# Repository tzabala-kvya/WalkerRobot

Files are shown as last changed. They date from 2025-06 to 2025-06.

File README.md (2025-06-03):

# Bluetooth-Controlled Two-Wheel Robot
Author: Tristan Zabala

Date: May 2025

Platform: Arduino Uno

Bluetooth Module: HM-10 (BLE)

Motor Driver: L298N Dual H-Bridge

Control App: Dabble (Gamepad Module)

## Overview
This project enables Bluetooth control of a two-wheel robot using the Dabble mobile app and an HM-10 BLE module. It lets you drive the robot forward, backward, left, and right, and adjust its speed in real time. An emergency stop is also built in for safety.

Features
🔼 Forward, 🔽 Backward, ◀️ Left, and ▶️ Right motion

🔄 Real-time speed control using Dabble Gamepad buttons:

Triangle: Increase speed

Cross: Decrease speed

Square: Reset speed to default (180)

Circle: Emergency stop (sets speed to 0)

📟 Serial Monitor feedback for debugging

🔧 Uses PWM to vary motor speed

## Required Libraries
Dabble Library

SoftwareSerial (included in Arduino IDE)

Install the Dabble library via the Arduino Library Manager or manually from the GitHub link above.

Wiring Diagram
Component	      Arduino Pin
HM-10 TX	      2 (RX via SoftwareSerial)
HM-10 RX	      3 (TX via SoftwareSerial)
HM-10 VCC       5V
HM-10 GND       GND
L298N IN1    	  6
L298N IN2	      7
L298N ENA       (PWM)	10
L298N IN3	      4
L298N IN4	      5
L298N ENB       (PWM)	9

Note: Use a proper power supply for motors; do not power them directly from the Arduino.

## How to Use
Upload the code to your Arduino Uno.

Open the Dabble app and navigate to the Gamepad module.

Connect via BLE to the HM-10 module.
  - If you're using the DSD TECH HM-10, the device will appear as "DSD Tech" in the Dabble app’s Bluetooth scan list. Make sure to select it to establish the connection.

Control the robot using the on-screen D-pad and buttons.

Open Serial Monitor (9600 baud) for live feedback on speed and actions.

Customization
Adjust Speed: Modify baseSpeed to change the robot's default speed.

Motor Logic: The setMotorDirection() function can be changed if your wiring requires reversing the polarity for proper motor direction.

## Troubleshooting

Motors not turning? 
  - Make sure all motor wiring and the external power supply are properly connected and delivering sufficient voltage.
  - Confirm that the L298N motor driver pins are correctly wired to the Arduino and match the pin numbers defined in the code

No response to Dabble? Ensure correct pins and baud rate in Dabble.begin().

License
This project is open-source under the MIT License.

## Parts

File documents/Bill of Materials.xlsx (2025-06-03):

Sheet: 1 Walker
Part Name | Model Quantity | Order Quantity/Walker | Cost(ea.) | Cost(tot.) | number/pack | Order Link
DriveSystem
12V 3000 mAhr Battery | 1 | 1 | $25.79 | $25.79 | 1 | TalentCell Rechargeable 12V DC Output Lithium ion Battery Pack (https://www.amazon.com/TalentCell-Rechargeable-Amplifier-Multi-led-Indicator/dp/B00MHNQIR2)
12V brushed DC motor with Encoder | 2 | 2 | $51.95 | $103.90 | 1 | 70:1 Metal Gearmotor 37Dx70L mm 12V with 64 CPR Encoder (Helical Pinion) (https://www.pololu.com/product/4754)
Arduino Mega 2560 | 1 | 1 | $48.99 | $48.99 | 1 | ARDUINO MEGA 2560 REV3 [A000067] (https://www.amazon.com/ARDUINO-MEGA-2560-REV3-A000067/dp/B0046AMGW0)
L298 Motor Drive Controller Board | 1 | 1 | $14.49 | $14.49 | 1 | L298 (https://www.amazon.com/DKARDU-Controller-Regulator-Optocoupler-Isolation/dp/B0B2RBXTYL?s=electronics)
Pixy2 Smart Vision Sensor | 1 | 1 | $69.90 | $69.90 | 1 | Pixy2 (https://www.amazon.com/Charmed-Labs-Pixy2-Vision-Sensor/dp/B07D1CLYD2)
Pan/Tilit Servo Motor Kit for Pixy2 | 1 | 1 | $29.90 | $29.90 | 1 | PixyCam Pan/Tilt Mount (https://www.amazon.com/Pan-Tilt2-Servo-Motor-Pixy2/dp/B07D1CWJTV?hvadid=309816945299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)
Motor bracket | 2 | 1 | $9.95 | $9.95 | 2 | Pololu Stamped Aluminum L-Bracket Pair for 37D mm Metal Gearmotors (https://www.pololu.com/product/1084)
Motor Mounting Spacer | 2 | 2 |  | $0.00 | 1 | 3D printing
Spur Gear 1.5 modules 39 teeth - TypeA | 2 | 2 |  | $0.00 | 1 | Laser cutting
Spur Gear 1.5 modules 46 teeth - TypeB | 4 | 4 |  | $0.00 | 1 | Laser cutting
Spur Gear 1.5 modules 30 teeth - TypeB | 4 | 4 |  | $0.00 | 1 | Laser cutting
HM-10 Bluetooth Modeule | 1 | 1 | $11.49 | $11.49 | 1 | DSD TECH HM-10 Master and Slave Bluetooth 4.0 LE iBeacon Module (https://www.amazon.com/DSD-TECH-HM-10-Bluetooth-Compatible/dp/B074VXZ1XZ)
ESP32 UWB | 3 | 3 | $39.80 | $119.40 | 1 | https://www.makerfabs.com/esp32-uwb-ultra-wideband.html
Intertial Measurement Unit (IMU) | 1 | 1 | $45.95 | $45.95 | 1 | Amazon.com: Adafruit 9-DOF Absolute Orientation IMU Fusion Breakout - BNO055 : Industrial & Scientific (https://www.amazon.com/Adafruit-Absolute-Orientation-Fusion-Breakout/dp/B017PEIGIG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)
Hardware
0.25in Ball Bearing GB | 8 | 1 | $11.49 | $11.49 | 10 | uxcell FR188-2RS Flanged Ball 1/4" x 1/2" x 3/16" Double Sealed (https://www.amazon.com/dp/B082PPK1L5/ref=emc_b_5_t)
0.25in D-shaft 1.35in | 8 | 8 | $1.39 | $11.12 | 1 | 0.250" (1/4") x 1.375" (1 3/8") Stainless Steel D-Shafting (https://www.servocity.com/0-250-1-4-x-1-375-1-3-8-stainless-steel-d-shafting/)
0.25in D-shaft 1.75in | 4 | 4 | $1.59 | $6.36 | 1 | 1/4" D-Shaft (Stainless Steel, 1-3/4" Length) (https://www.servocity.com/0-250-1-4-x-1-75-1-3-4-stainless-steel-d-shafting/)
0.25in D-shaft 1in | 4 | 4 | $1.19 | $4.76 | 1 | 1/4" D-Shaft (Stainless Steel, 1" Length) (https://www.servocity.com/0-250-1-4-x-1-00-stainless-steel-d-shafting/)
0.25in Non-Flange Ball Bearing | 24 | 12 | $2.19 | $26.28 | 2 | 1/4" ID Non-Flanged Ball Bearing (3/8" OD, 1/8" Thickness) - 2 Pack - ServoCity (https://www.servocity.com/1-4-id-x-3-8-od-non-flanged-ball-bearing-2-pack/)
0.25in Hub M3 Holes | 24 | 12 | $9.95 | $119.40 | 2 | Pololu Universal Aluminum Mounting Hub for 1/4″ (6.35mm) Shaft, M3 Holes (2-Pack) (https://www.pololu.com/product/1994/resources)
3mm Ball Bearing (3mmx8mmx4mm) | 96 | 3 | $11.99 | $35.97 | 20 | Kozelo 20pcs F693ZZ Flanged Ball Bearing - [3x8x4mm] (https://www.amazon.com/Kozelo-20pcs-F693ZZ-Flanged-Bearing/dp/B0B8BSCHXS)
0.25in Shaft Collar | 8 | 2 | $7.99 | $15.98 | 4 | AZSSMUK 1/4" Bore Solid Steel Style Zinc Plated Set Screw Shaft Collars (https://www.amazon.com/Aobbmok-Solid-Steel-Plated-Collars/dp/B07BTV2WQW)
M3 Steel Hex Nut | 52 | 1 | $4.73 | $4.73 | 100 | 18-8 Stainless Steel Hex Nut, M3 x 0.5 mm Thread (https://www.mcmaster.com/products/hex-nuts/?s=steel+hex+nuts)
M3*6 mm Steel Pan Head Phillips Screw | 8 | 1 | $7.03 | $7.03 | 100 | Passivated 18-8 Stainless Steel Pan Head Phillips Screws, M3 x 0.5mm Thread, 6mm Long (https://www.mcmaster.com/92000A116/)
M3*12 mm Steel Pan Head Phillips Screw | 84 | 1 | $6.65 | $6.65 | 100 | Passivated 18-8 Stainless Steel Pan Head Phillips Screws M3 x 0.5mm Thread, 12mm Long (https://www.mcmaster.com/92000A122/)
M3*16 mm Steel Pan Head Phillips Screw | 28 | 1 | $7.60 | $7.60 | 100 | Passivated 18-8 Stainless Steel Pan Head Phillips Screws M3 x 0.5mm Thread, 16mm Long (https://www.mcmaster.com/92000A126/)
M3*25 mm Steel Pan Head Phillips Screw | 24 | 1 | $8.83 | $8.83 | 100 | Passivated 18-8 Stainless Steel Pan Head Phillips Screws M3 x 0.5mm Thread, 25mm Long (https://www.mcmaster.com/92000A130/)
M3*30 mm Steel Pan Head Phillips Screw | 8 | 1 | $9.38 | $9.38 | 100 | Passivated 18-8 Stainless Steel Pan Head Phillips Screws M3 x 0.5mm Thread, 30mm Long (https://www.mcmaster.com/92000A132/)
M3*45 mm Steel Pan Head Phillips Screw | 4 | 1 | $15.80 | $15.80 | 100 | Passivated 18-8 Stainless Steel Pan Head Phillips Screws M3 x 0.5mm Thread, 45mm Long (https://www.mcmaster.com/92000A138/)
M3 Washer | 24 | 1 | $3.42 | $3.42 | 100 | General Purpose 18-8 Stainless Steel Washer for M3 Screw Size, 3.200 mm ID, 6 mm OD (https://www.mcmaster.com/98689A112/)
Hub 6mm ID, 10mm length | 2 | 1 | $8.49 | $8.49 | 4 | Sydien 4Pcs Silver 6mm Rigid Flange Shaft Coupling Motor Guide (https://www.amazon.com/dp/B07R77ZGNN/ref=twister_B07R459BG7?_encoding=UTF8&th=1)
M3 Nut Strip - 56mm | 4 | 2 | $3.50 | $7.00 | 1 | M3 Nut Strip - 56mm (https://www.revrobotics.com/rev-41-1733/)
M3 x 100mm Fully Threaded Rod | 4 | 1 | $10.19 | $10.19 | 15 | uxcell 15Pcs M3 x 100mm Fully Threaded Rod (https://www.amazon.com/uxcell-Threaded-Stainless-Threads-M3-0-5/dp/B09L7R8NRQ?s=hi)
Outside Gear Cover | 4 | 4 |  | $0.00 | 1 | 3D printing
Spacer 12.73mm | 12 | 12 |  | $0.00 | 1 | 3D printing
Spacer 19.74mm | 4 | 4 |  | $0.00 | 1 | 3D printing
Spacer 1mm GB | 8 | 8 |  | $0.00 | 1 | 3D printing
Spacer 2mm | 32 | 32 |  | $0.00 | 1 | 3D printing
Spacer 7.2mm | 8 | 8 |  | $0.00 | 1 | 3D printing
Spacer 7.73mm | 8 | 8 |  | $0.00 | 1 | 3D printing
Spacer 9mm | 8 | 8 |  | $0.00 | 1 | 3D printing
Links
Binary Link 1 | 16 | 16 |  | $0.00 | 1 | Laser cutting
Binary Link 2 | 8 | 8 |  | $0.00 | 1 | Laser cutting
Foot | 16 | 16 |  | $0.00 | 1 | Laser cutting
Ternary links-crank | 16 | 16 |  | $0.00 | 1 | Laser cutting
Ternary links | 8 | 8 |  | $0.00 | 1 | Laser cutting
Structure
AT-AT Side-6mm*12'*20' Wood | 2 | 2 |  | $0.00 | 1 | Laser cutting
Chassis base-6mm*6'*15' Wood | 1 | 1 |  | $0.00 | 1 | Laser cutting
 |  |  | Single Walker Cost |  | $800.24

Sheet: Class Walker
Part Name | Model Quantity | # of Walkers | # / Pack | # of Packs | Cost(ea.) | Cost(tot.) | Order Link
DriveSystem
12V 3000 mAhr Battery | 1 | 4 | 1 | 1 | $25.79 | $25.79 | TalentCell Rechargeable 12V DC Output Lithium ion Battery Pack (https://www.amazon.com/TalentCell-Rechargeable-Amplifier-Multi-led-Indicator/dp/B00MHNQIR2)
12V brushed DC motor with Encoder | 2 |  | 1 | 2 | $51.95 | $103.90 | 70:1 Metal Gearmotor 37Dx70L mm 12V with 64 CPR Encoder (Helical Pinion) (https://www.pololu.com/product/4754)
Arduino UNO | 1 |  | 1 | 1 | $48.99 | $48.99 | Arduino UNO (https://www.digikey.com/en/products/detail/arduino/ABX00080/20371542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)
L298 Motor Drive Controller Board | 1 |  | 2 | 1 | $7.00 | $7.00 | L298N (https://www.amazon.com/Controller-H-Bridge-Stepper-Control-Mega2560/dp/B0DPPWFZ1C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)
Motor bracket | 2 |  | 2 | 1 | $20.00 | $20.00 | Pololu Stamped Aluminum L-Bracket Pair for 37D mm Metal Gearmotors (https://www.pololu.com/product/1084)
Motor Mounting Spacer | 2 |  | 1 | 2 |  | $0.00 | 3D printing
Spur Gear 1.5 modules 39 teeth - TypeA | 2 |  | 1 | 2 |  | $0.00 | Laser cutting
Spur Gear 1.5 modules 46 teeth - TypeB | 4 |  | 1 | 4 |  | $0.00 | Laser cutting
Spur Gear 1.5 modules 30 teeth - TypeB | 4 |  | 1 | 4 |  | $0.00 | Laser cutting
HM-10 Bluetooth Modeule | 1 |  | 1 | 1 | $11.49 | $11.49 | DSD TECH HM-10 Master and Slave Bluetooth 4.0 LE iBeacon Module (https://www.amazon.com/DSD-TECH-HM-10-Bluetooth-Compatible/dp/B074VXZ1XZ)
Hardware
0.25in Ball Bearing GB | 8 | 4 | 10 | 1 | $11.49 | $11.49 | uxcell FR188-2RS Flanged Ball 1/4" x 1/2" x 3/16" Double Sealed (https://www.amazon.com/dp/B082PPK1L5/ref=emc_b_5_t)
0.25in D-shaft 1.35in | 8 |  | 1 | 8 | $1.39 | $11.12 | 0.250" (1/4") x 1.375" (1 3/8") Stainless Steel D-Shafting (https://www.servocity.com/0-250-1-4-x-1-375-1-3-8-stainless-steel-d-shafting/)
0.25in D-shaft 1.75in | 4 |  | 1 | 4 | $1.59 | $6.36 | 1/4" D-Shaft (Stainless Steel, 1-3/4" Length) (https://www.servocity.com/0-250-1-4-x-1-75-1-3-4-stainless-steel-d-shafting/)
0.25in D-shaft 1in | 4 |  | 1 | 4 | $1.19 | $4.76 | 1/4" D-Shaft (Stainless Steel, 1" Length) (https://www.servocity.com/0-250-1-4-x-1-00-stainless-steel-d-shafting/)
0.25in Non-Flange Ball Bearing | 24 |  | 2 | 12 | $2.19 | $26.28 | 1/4" ID Non-Flanged Ball Bearing (3/8" OD, 1/8" Thickness) - 2 Pack - ServoCity (https://www.servocity.com/1-4-id-x-3-8-od-non-flanged-ball-bearing-2-pack/)
0.25in Hub M3 Holes | 24 |  | 2 | 12 | $9.95 | $119.40 | Pololu Universal Aluminum Mounting Hub for 1/4″ (6.35mm) Shaft, M3 Holes (2-Pack) (https://www.pololu.com/product/1994/resources)
3mm Ball Bearing (3mmx8mmx4mm) | 96 |  | 20 | 5 | $11.99 | $59.95 | Kozelo 20pcs F693ZZ Flanged Ball Bearing - [3x8x4mm] (https://www.amazon.com/Kozelo-20pcs-F693ZZ-Flanged-Bearing/dp/B0B8BSCHXS)
0.25in Shaft Collar | 8 |  | 4 | 2 | $7.99 | $15.98 | AZSSMUK 1/4" Bore Solid Steel Style Zinc Plated Set Screw Shaft Collars (https://www.amazon.com/Aobbmok-Solid-Steel-Plated-Collars/dp/B07BTV2WQW)
M3 Steel Hex Nut | 52 |  | 100 | 1 | $4.73 | $4.73 | 18-8 Stainless Steel Hex Nut, M3 x 0.5 mm Thread (https://www.mcmaster.com/products/hex-nuts/?s=steel+hex+nuts)
M3*6 mm Steel Pan Head Phillips Screw | 8 |  | 100 | 1 | $7.03 | $7.03 | Passivated 18-8 Stainless Steel Pan Head Phillips Screws, M3 x 0.5mm Thread, 6mm Long (https://www.mcmaster.com/92000A116/)
M3*12 mm Steel Pan Head Phillips Screw | 84 |  | 100 | 1 | $6.65 | $6.65 | Passivated 18-8 Stainless Steel Pan Head Phillips Screws M3 x 0.5mm Thread, 12mm Long (https://www.mcmaster.com/92000A122/)
M3*16 mm Steel Pan Head Phillips Screw | 28 |  | 100 | 1 | $7.60 | $7.60 | Passivated 18-8 Stainless Steel Pan Head Phillips Screws M3 x 0.5mm Thread, 16mm Long (https://www.mcmaster.com/92000A126/)
M3*25 mm Steel Pan Head Phillips Screw | 24 |  | 100 | 1 | $8.83 | $8.83 | Passivated 18-8 Stainless Steel Pan Head Phillips Screws M3 x 0.5mm Thread, 25mm Long (https://www.mcmaster.com/92000A130/)
M3*30 mm Steel Pan Head Phillips Screw | 8 |  | 100 | 1 | $9.38 | $9.38 | Passivated 18-8 Stainless Steel Pan Head Phillips Screws M3 x 0.5mm Thread, 30mm Long (https://www.mcmaster.com/92000A132/)
M3*45 mm Steel Pan Head Phillips Screw | 4 |  | 100 | 1 | $15.80 | $15.80 | Passivated 18-8 Stainless Steel Pan Head Phillips Screws M3 x 0.5mm Thread, 45mm Long (https://www.mcmaster.com/92000A138/)
M3 Washer | 24 |  | 100 | 1 | $3.42 | $3.42 | General Purpose 18-8 Stainless Steel Washer for M3 Screw Size, 3.200 mm ID, 6 mm OD (https://www.mcmaster.com/98689A112/)
Hub 6mm ID, 10mm length | 2 |  | 4 | 1 | $8.49 | $8.49 | Sydien 4Pcs Silver 6mm Rigid Flange Shaft Coupling Motor Guide (https://www.amazon.com/dp/B07R77ZGNN/ref=twister_B07R459BG7?_encoding=UTF8&th=1)
M3 Nut Strip - 56mm | 4 |  | 1 | 4 | $3.50 | $14.00 | M3 Nut Strip - 56mm (https://www.revrobotics.com/rev-41-1733/)
M3 x 100mm Fully Threaded Rod | 4 |  | 15 | 1 | $10.19 | $10.19 | uxcell 15Pcs M3 x 100mm Fully Threaded Rod (https://www.amazon.com/uxcell-Threaded-Stainless-Threads-M3-0-5/dp/B09L7R8NRQ?s=hi)
Outside Gear Cover | 4 |  | 1 | 4 |  | $0.00 | 3D printing
Spacer 12.73mm | 12 |  | 1 | 12 |  | $0.00 | 3D printing
Spacer 19.74mm | 4 |  | 1 | 4 |  | $0.00 | 3D printing
Spacer 1mm GB | 8 |  | 1 | 8 |  | $0.00 | 3D printing
Spacer 2mm | 32 |  | 1 | 32 |  | $0.00 | 3D printing
Spacer 7.2mm | 8 |  | 1 | 8 |  | $0.00 | 3D printing
Spacer 7.73mm | 8 |  | 1 | 8 |  | $0.00 | 3D printing
Spacer 9mm | 8 |  | 1 | 8 |  | $0.00 | 3D printing
Links
Binary Link 1 | 16 | 4 | 1 | 16 |  | $0.00 | Laser cutting
Binary Link 2 | 8 |  | 1 | 8 |  | $0.00 | Laser cutting
Foot | 16 |  | 1 | 16 |  | $0.00 | Laser cutting
Ternary links-crank | 16 |  | 1 | 16 |  | $0.00 | Laser cutting
Ternary links | 8 |  | 1 | 8 |  | $0.00 | Laser cutting
Structure
Appa Side-6mm*12'*20' Wood | 2 | 4 | 1 | 2 |  | $0.00 | Laser cutting
Chassis base-6mm*6'*15' Wood | 1 |  | 1 | 1 |  | $0.00 | Laser cutting
 |  |  |  |  |  | $568.63

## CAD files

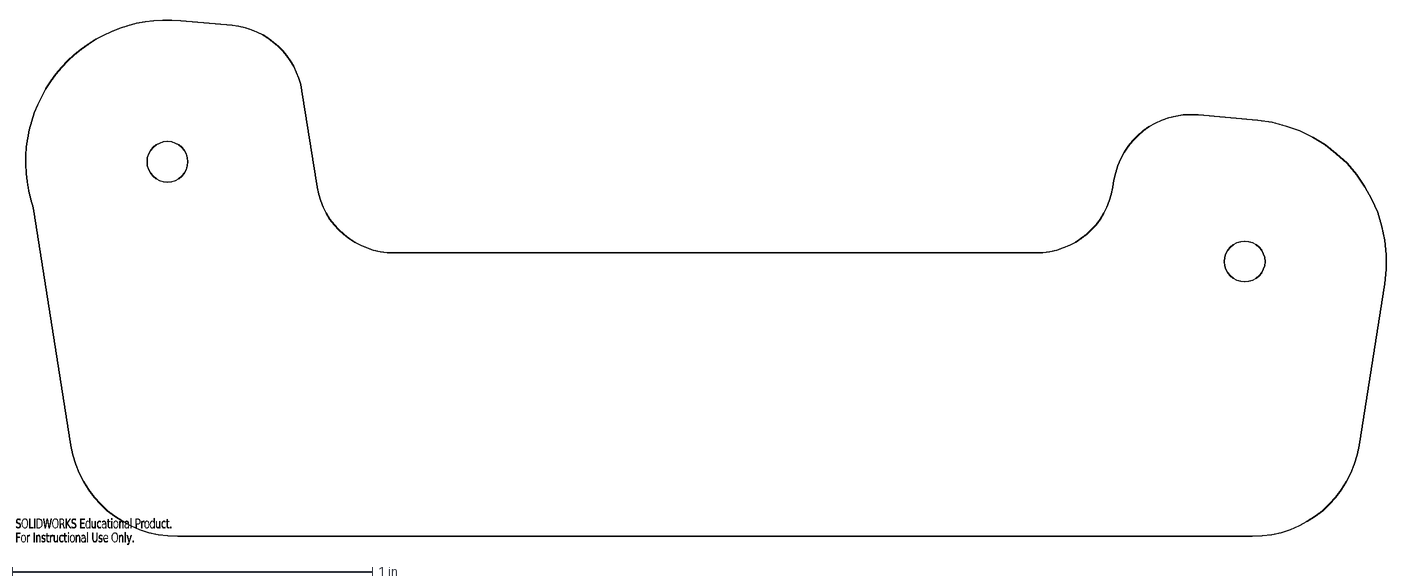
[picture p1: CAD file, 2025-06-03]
Parts - DXF Files/Foot.DXF
SOLIDWORKS Educational Product.
For Instructional Use Only.

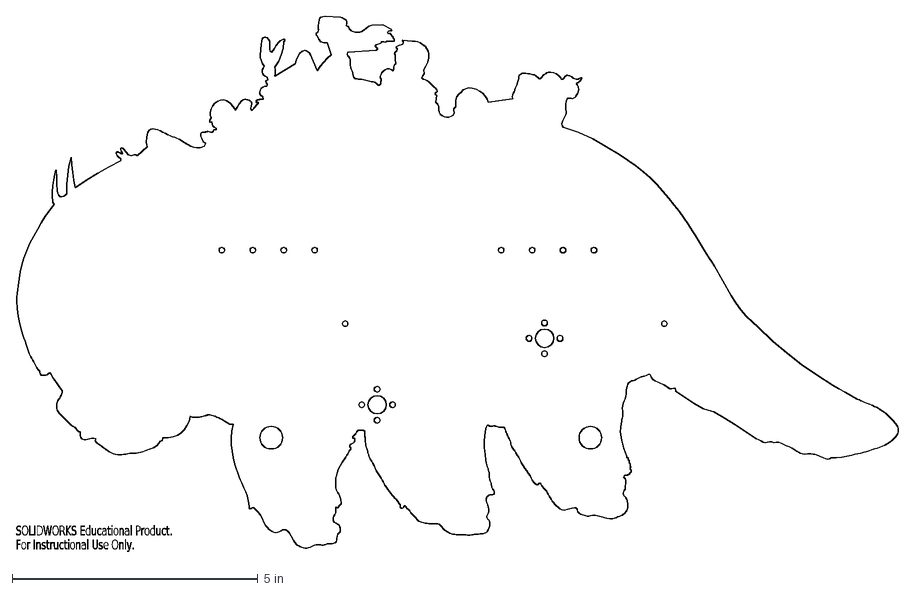
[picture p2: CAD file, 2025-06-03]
Parts - DXF Files/appa walker chassis.DXF
SOLIDWORKS Educational Product.
For Instructional Use Only.

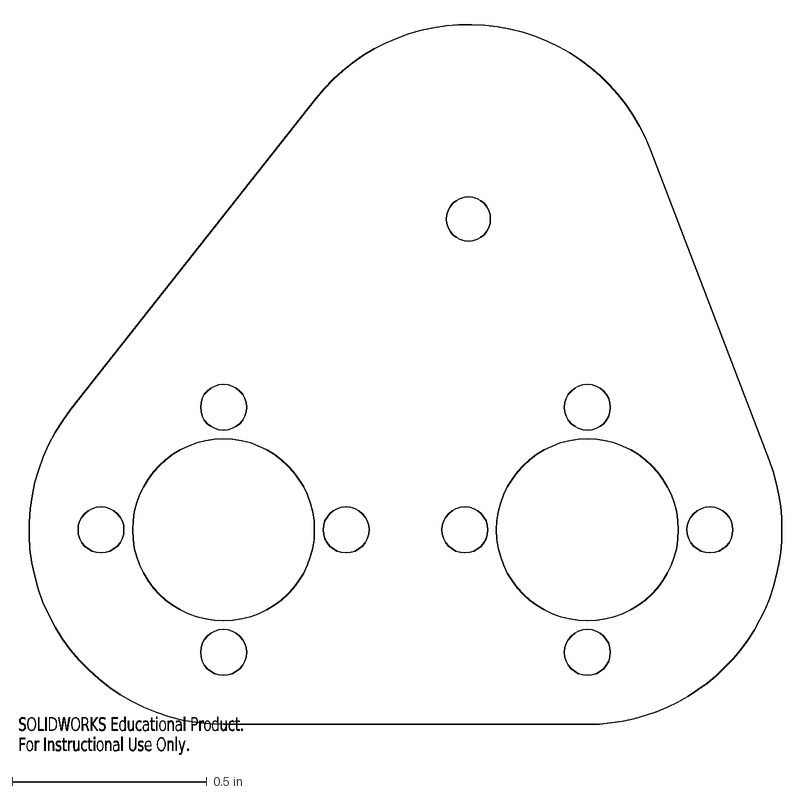
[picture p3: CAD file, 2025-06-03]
Parts - DXF Files/Ternary Link - crank.DXF
SOLIDWORKS Educational Product.
For Instructional Use Only.

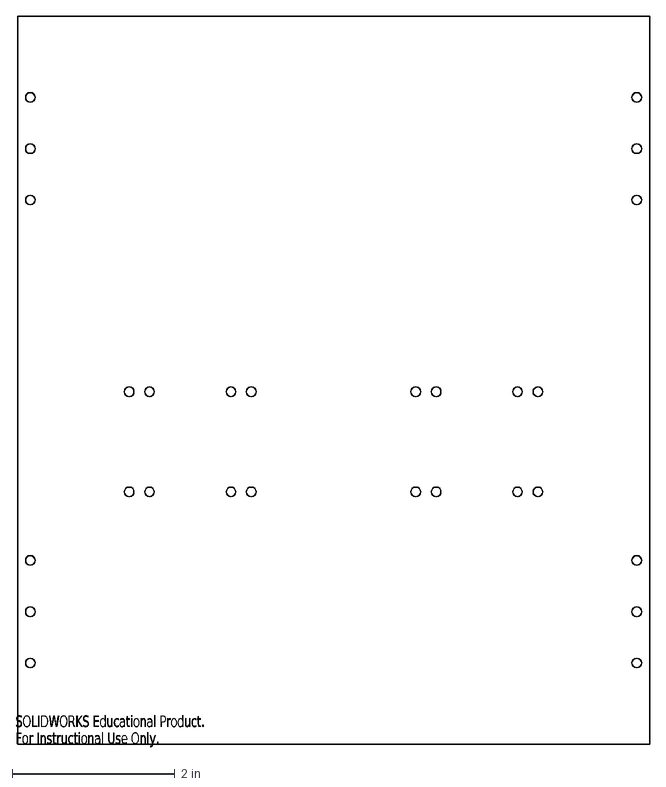
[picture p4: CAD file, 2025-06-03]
Parts - DXF Files/Chassis Base.DXF
SOLIDWORKS Educational Product.
For Instructional Use Only.

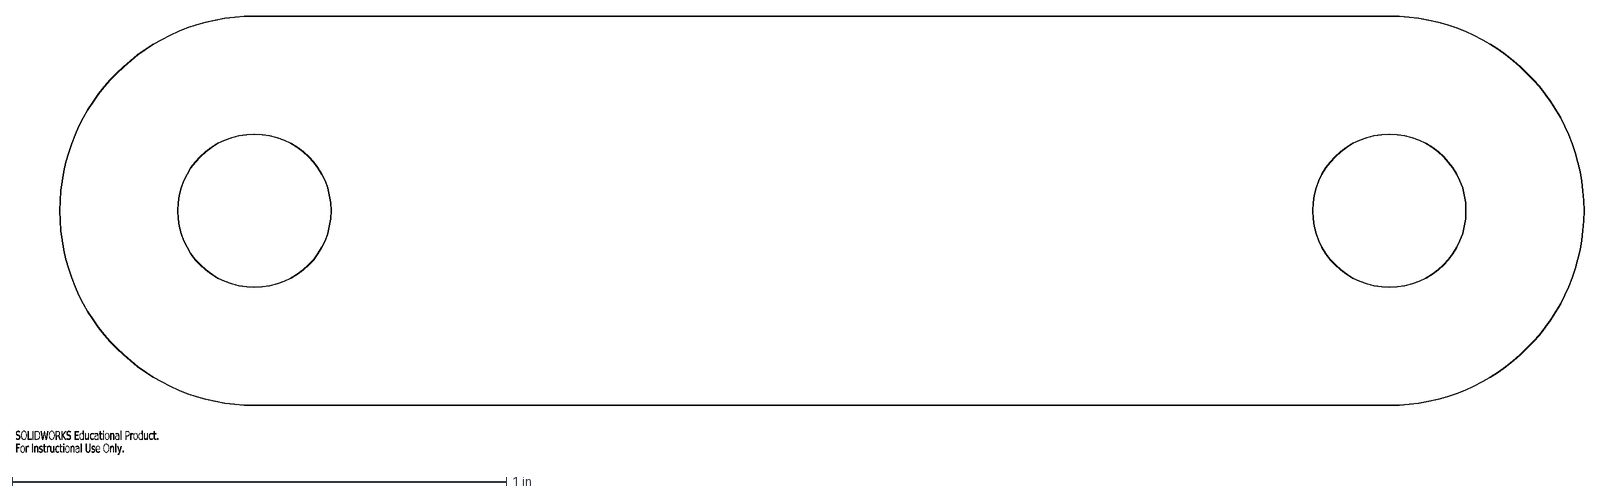
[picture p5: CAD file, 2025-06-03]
Parts - DXF Files/Binary Link 2.DXF
SOLIDWORKS Educational Product.
For Instructional Use Only.

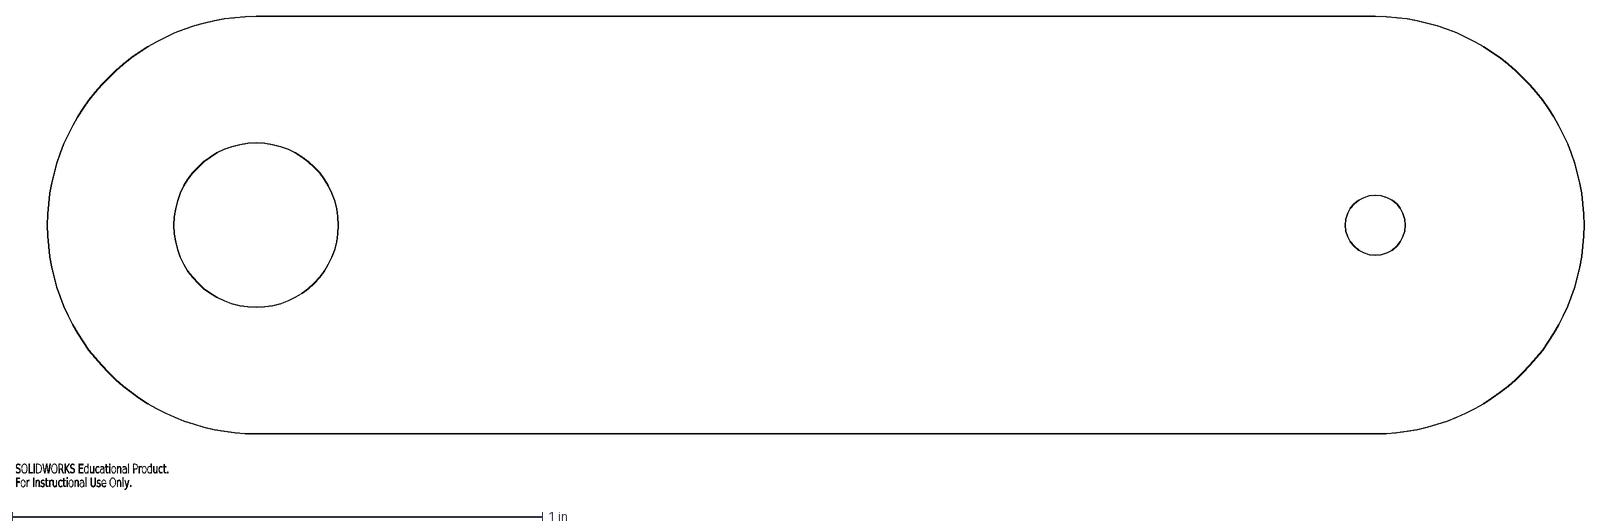
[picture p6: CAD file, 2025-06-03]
Parts - DXF Files/Binary Link 1.DXF
SOLIDWORKS Educational Product.
For Instructional Use Only.

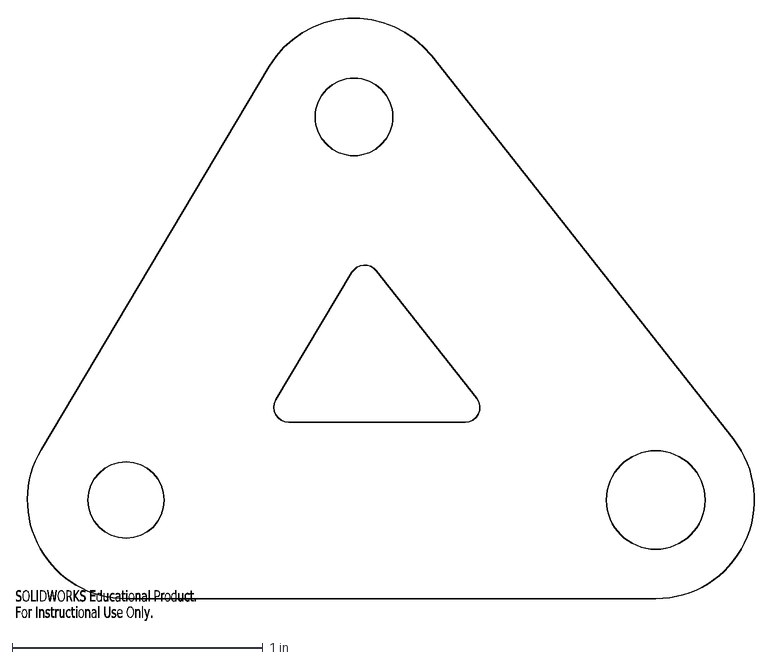
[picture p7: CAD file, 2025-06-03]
Parts - DXF Files/Ternary Link.DXF
SOLIDWORKS Educational Product.
For Instructional Use Only.

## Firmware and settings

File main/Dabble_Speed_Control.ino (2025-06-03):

/*
  Project: Bluetooth-Controlled Two-Wheel Robot
  Author: Tristan Zabala
  Date: May 2025
  Board: Arduino Uno
  Bluetooth Module: HM-10 (BLE)
  Motor Driver: L298N Dual H-Bridge
  Control App: Dabble (Gamepad Module)

  Description:
  This project enables wireless control of a two-wheel robot using the Dabble mobile app via Bluetooth Low Energy (BLE).
  The robot's movement and speed are managed through the Gamepad module in Dabble, allowing for real-time adjustments.
  The L298N motor driver facilitates direction and speed control of the DC motors through PWM signals.

  Features:
  - Forward, backward, left, and right movement control
  - Adjustable speed using Gamepad buttons
  - Emergency stop functionality
  - Real-time feedback via Serial Monitor

  Libraries Required:
  - Dabble: https://github.com/TinkerHub/Dabble
  - SoftwareSerial (built-in with Arduino IDE)

  Wiring Overview:
  - HM-10 TX → Arduino Pin 2 (SoftwareSerial RX)
  - HM-10 RX → Arduino Pin 3 (SoftwareSerial TX)
  - L298N IN1 → Arduino Pin 10
  - L298N IN2 → Arduino Pin 7
  - L298N ENA → Arduino Pin 9 (PWM)
  - L298N IN3 → Arduino Pin 4
  - L298N IN4 → Arduino Pin 5
  - L298N ENB → Arduino Pin 9 (PWM)

  Notes:
  - Ensure the HM-10 module is properly configured for BLE communication.
  - Verify motor connections and power supply are adequate for the motors used.
  - Adjust 'baseSpeed' variable as needed to suit your specific motor characteristics.
*/

#include <Dabble.h>
#include <SoftwareSerial.h>


// Motor A (left)
#define IN1 6
#define IN2 7
#define ENA 10  // PWM

// Motor B (right)
#define IN3 4
#define IN4 5
#define ENB 9 // PWM

int baseSpeed = 180;  // Adjustable motor speed
bool prevTriangle = false;
bool prevCross = false;
bool prevSquare = false;
bool prevCircle = false;


void setup() {
  pinMode(IN1, OUTPUT);
  pinMode(IN2, OUTPUT);
  pinMode(ENA, OUTPUT);
  pinMode(IN3, OUTPUT);
  pinMode(IN4, OUTPUT);
  pinMode(ENB, OUTPUT);

  // Connect HM-10 RXD to Pin 3
  // Conenct HM-10 TXD to Pin 2
  Dabble.begin(9600, 2, 3);  // Dabble on HM-10
  Serial.begin(9600);
  Serial.println("Dabble Gamepad Control with Speed Adjustment");
}

void loop() {
  Dabble.processInput();

  bool triangle = GamePad.isTrianglePressed();
  bool cross = GamePad.isCrossPressed();
  bool square = GamePad.isSquarePressed();
  bool circle = GamePad.isCirclePressed();

  // Triangle: Increase speed
  if (triangle && !prevTriangle) {
    baseSpeed += 10;
    if (baseSpeed > 255) baseSpeed = 255;
    Serial.print("Speed increased to ");
    Serial.println(baseSpeed);
  }

  // Cross: Decrease speed
  if (cross && !prevCross) {
    baseSpeed -= 10;
    if (baseSpeed < 0) baseSpeed = 0;
    Serial.print("Speed decreased to ");
    Serial.println(baseSpeed);
  }

  // Square: Reset speed
  if (square && !prevSquare) {
    baseSpeed = 180;
    Serial.println("Speed reset to 180");
  }

  // Circle: Emergency stop
  if (circle && !prevCircle) {
    baseSpeed = 0;
    Serial.println("Emergency stop");
  }

  // Update previous states
  prevTriangle = triangle;
  prevCross = cross;
  prevSquare = square;
  prevCircle = circle;


  int leftSpeed = 0;
  int rightSpeed = 0;

  if (GamePad.isUpPressed()) {
    Serial.println("Forward");
    setMotorDirection(true, true);
    leftSpeed = baseSpeed;
    rightSpeed = baseSpeed;
  } else if (GamePad.isDownPressed()) {
    Serial.println("Backward");
    setMotorDirection(false, false);
    leftSpeed = baseSpeed;
    rightSpeed = baseSpeed;
  } else if (GamePad.isLeftPressed()) {
    Serial.println("Turn Left");
    setMotorDirection(true, false);
    leftSpeed = baseSpeed;
    rightSpeed = baseSpeed;
  } else if (GamePad.isRightPressed()) {
    Serial.println("Turn Right");
    setMotorDirection(false, true);
    leftSpeed = baseSpeed;
    rightSpeed = baseSpeed;
  } else {
    setMotorDirection(false, false);
    leftSpeed = 0;
    rightSpeed = 0;
  }

  analogWrite(ENA, leftSpeed);
  analogWrite(ENB, rightSpeed);
//  Serial.print("Left PWM: ");
//  Serial.println(leftSpeed);
//  Serial.print("Right PWM: ");
//  Serial.println(rightSpeed);

}

void setMotorDirection(bool leftForward, bool rightForward) {
  digitalWrite(IN1, leftForward ? HIGH : LOW);
  digitalWrite(IN2, leftForward ? LOW : HIGH);
  digitalWrite(IN3, rightForward ? HIGH : LOW);
  digitalWrite(IN4, rightForward ? LOW : HIGH);
}
